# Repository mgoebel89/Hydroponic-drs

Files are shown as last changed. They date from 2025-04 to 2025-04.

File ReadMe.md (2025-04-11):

# What the project is about

**DISCLEMER:** This project was first and foremost created as a workshop for the **"SMART GREEN ISLAND MAKEATHON 2025 on Gran Canaria."**

Therefore, please keep the following in mind:

- The workshop was designed for students aged 15 to 17.

- The project served as an introduction to the world of technology for students.

- Based on the two points mentioned above, the hydroponic system is intentionally designed to be minimalistic. The system was not designed or tested for long-term use, though it is fully automatic and functional.

- Since the workshop was conducted by coaches who assisted the participants at every step, the provided instructions, explanations, files, and plans may leave some aspects out or be incomplete.

- The provided documentation may contain seemingly unnecessary information that is not vital to the assembly

## This guide will show you

- How to build a hydroponic system yourself and how to apply technological methods such as:
  - ESP32 Microcontroller programming in Micropython
  - Implementing PH and EC sensors
- Essential knowledge & concepts to apply or perhaps even expand upon your own hydroponic projects  

## Prerequisites

- Soldering equipment
- Basic coding knowledge
- 3D printer

## Quicklinks

[Bill of materials](BoM.md)

- List of required components and parts to get started

[Build instructions](construction/Instructions.md)

- Instrunctions with images

[3D-Printed Parts](parts)

- Required 3D-printed parts to build the hydroponic system

[Electronics](electronics)

- PH-Probe Instructions
- Additional knowledge on pH-values and conductivity

[Software](src)

- Micropython code for the ESP32 microcontroller

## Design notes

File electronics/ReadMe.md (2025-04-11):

# Details on the sensors can be found under

- [EC](EC-Probe.md)
- [PH](PH-Probe.md)

the `ibom.html` contains the BoM of the PCB and a plan for setting the PCB components.

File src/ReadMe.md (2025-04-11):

# This folder contains source files for different usecases

- `time_control.py` is ment to periodicaly fill the container and let it empty out.
  - the time it takes to fill and empty have to be measured and updated in the code manually.
  - `time_on` should be just over the time it takes for the container to start draining.
  - `time_off` should be set to the time it takes for the system to drain added to the time you want between system flushes
  - sugested flush timing, once every 30 minutes
- `calibrate_ph.py` for usage see [PH-Probe](../electronics/PH-Probe.md)
- `fill_sense_control.py` is a more sophisticated version of `time_control.py` that detects waterlevel and automatically fills the container when it is empty and stops when it is full.
  - for instructions on how to set up the sensor see [FillSense](../construction/FillSense.md)

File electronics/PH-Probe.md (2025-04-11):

# PH Probe Instructions

**The E-201-C sensor is not suitable for continuous deployment**, it should only be used to sporadically measure PH when refining water.

The PH-Probe has to be calibrated using `calibrate_ph.py`\

1. Connect the probe to the normalizer board.
2. Connect the normalizer board to the control-PCB.
3. Run the `calibrate_ph.py` script on the controller.
4. Put the probe into a solution with a known PH.
5. Use the potentiometer on the normalizer board to adjust the PH output to match the solution's PH.

for more details on ideal values, see [pH-values](PH and Conductivity.md)

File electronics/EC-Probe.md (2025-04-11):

# EC Probe Disclaimer

The EC-Probe (TDS sensor) depends on temperature measurements and can, therefore not be used with the current setup.

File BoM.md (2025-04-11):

# Parts and components

## Tables of content

| Electronic Components | Requirements |
|---|---|
| ESP 32 Microcontroller | ESPRESSIF C6-Mini-1|
| 5V Waterpump |USB-A, 1-3W|
| PH-Sensor |E-201-C, 3.3V|
| EC Sensor |TDS, 3.3V|
| **Electric Components**| |
| Powersupply 5V | minimum 5W, USB-A|
| USB-C Cable (Male-Female) |-|
| Breakaway board header | Female, 2.54mm, 15 Pins per Side|
| **Biological Components** | |
| Seedlings|Only leafy plants, take its size into account |
| Granules | Clay granules for potted plants |
| Fertilizer |-|
| **Tools** ||
| Drill |-|
| Isolating Tape |-|
| Sidecutters |-|
| Pliers |-|
| Soldering station |-|
| Tinsolder |-|
| O-Ringe |Amount: 4 per system, Outer diameter 20mm, Inner diameter 15mm|
| **Exterior** | |
| Containers | Not translucent, as dark as possible|
| Silicon Hose | Inner diameter 8mm|
| **3D Printing**| |
| 3D-Printing filament | - |
| **Interior** | |
|Netpot|-|

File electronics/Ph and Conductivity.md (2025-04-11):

# PH and Conductivity in hydroponic systems 

### PH Values

PH-values for leafy plants range between 5 (typically 5.5) and 7.

### Electrical Conductivity

Typical conductivity values for hydroponic systems fall between 1.500 and 2.500 microSiemens per cm (µS/cm).

Our readings are limited to ppm measurements therefore conversion rates from ppm to µS/cm and ppm to mg/L(Salts) are needed.

The following conversions are rough approximations:

- 1 ppm ≈ 1 mg/L
- 1 ppm ≈ 1.5625 µS/cm (640 scale) 

### Plant growth stages

Optimal PPM readings increase according to the plant's growth stage. 
These ranges can be found online.

### How to interpret value readings

Conductivity measurements indicate total amounts of salts in the water such as:

- Nitrogen
- Phosphorus
- Potassium

### Methods to adjust PH and EC

Most simple method is to dillute the nutrient solution by replacing or adding more water.

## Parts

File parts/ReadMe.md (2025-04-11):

# Required number of components for one system: 

1x Drilling template (Drilling_template.3mf)

1x Siphon (Siphon.3mf)

1x Siphon cap (Cap.3mf)

2x Siphon house-adapter (House_adapter.3mf)

1-5x Pot holder (Netpot_holder.3mf)

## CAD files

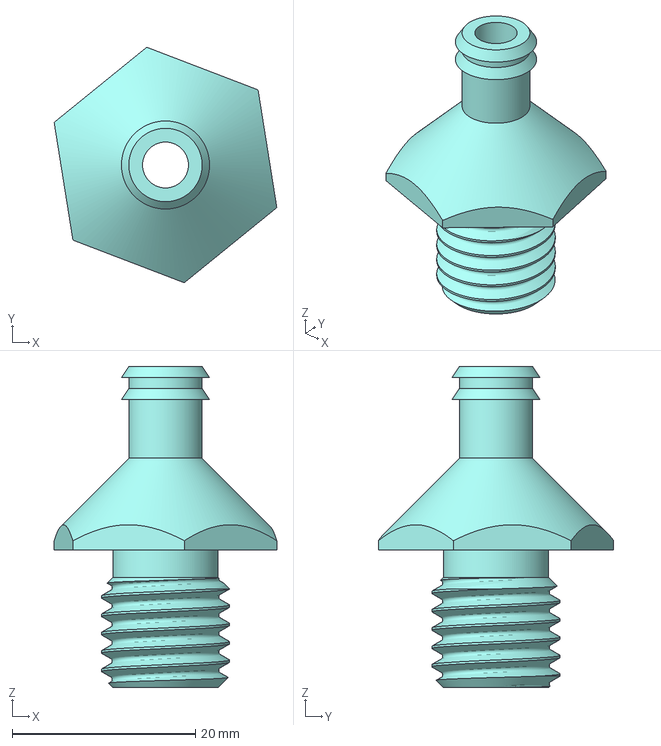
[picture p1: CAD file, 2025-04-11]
parts/Hose_adapter.3mf
24.3 x 25.7 x 35.0 mm

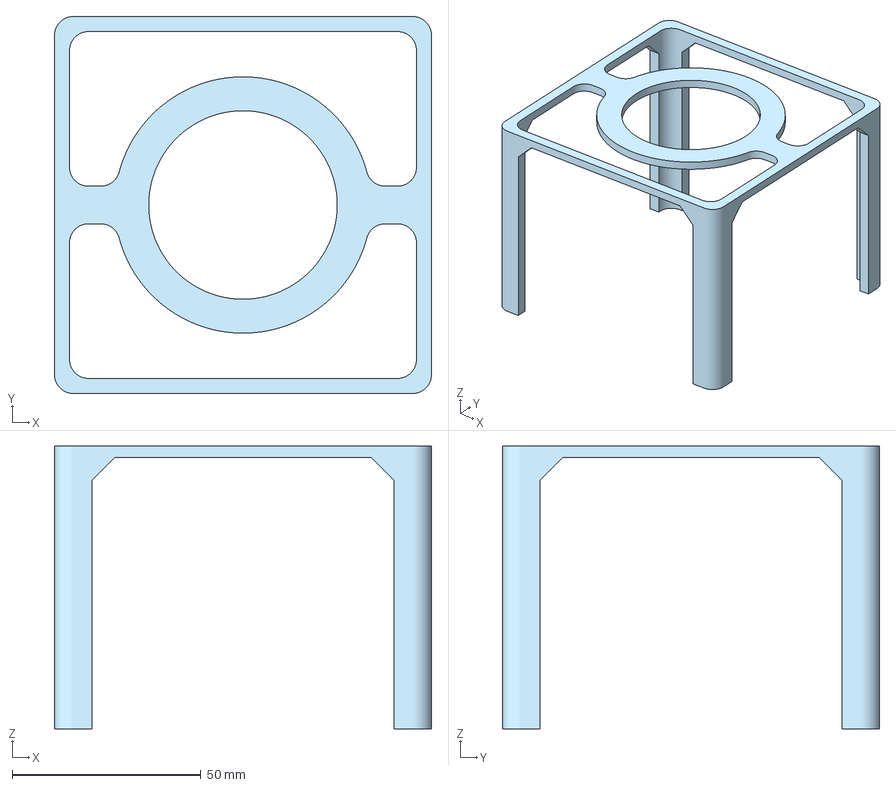
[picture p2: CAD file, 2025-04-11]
parts/Netpot_holder.3mf
100.0 x 100.0 x 75.0 mm

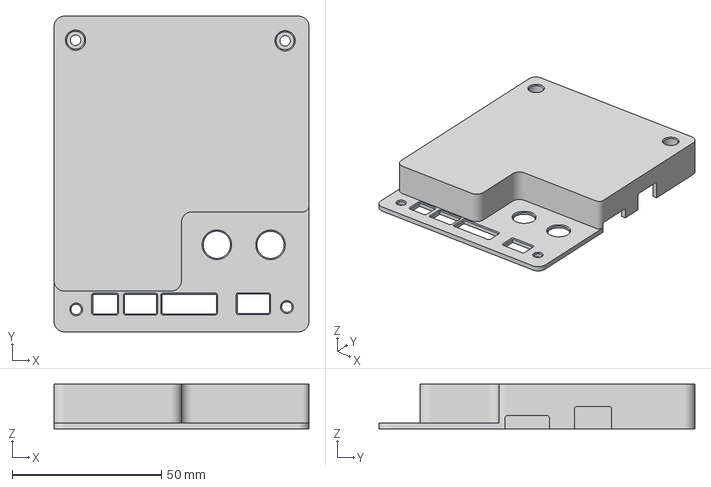
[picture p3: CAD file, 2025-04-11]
parts/Control_board_cover_bottom.3mf
85.4 x 105.7 x 15.0 mm

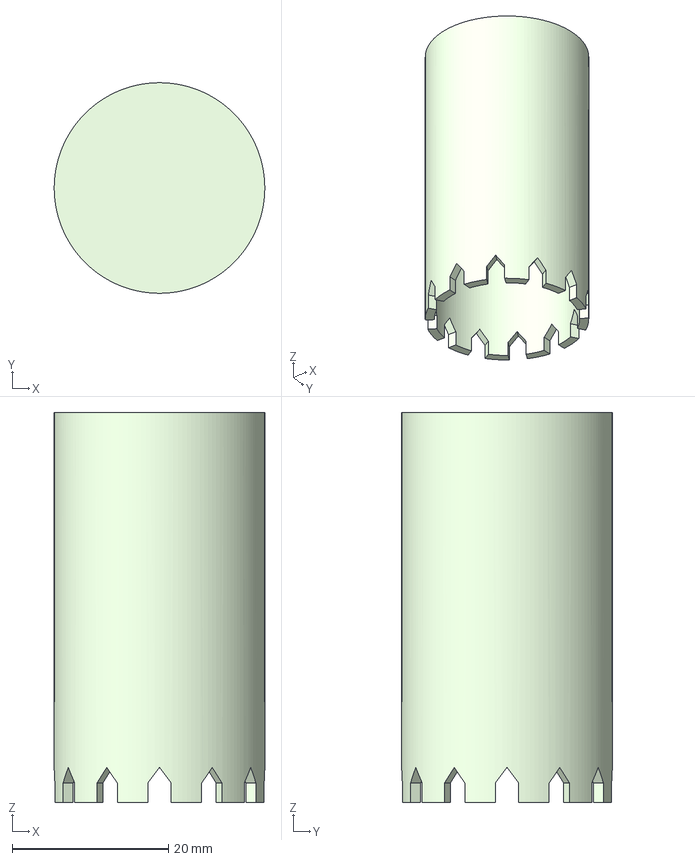
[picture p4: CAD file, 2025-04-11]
parts/Cap.3mf
27.0 x 27.0 x 50.0 mm

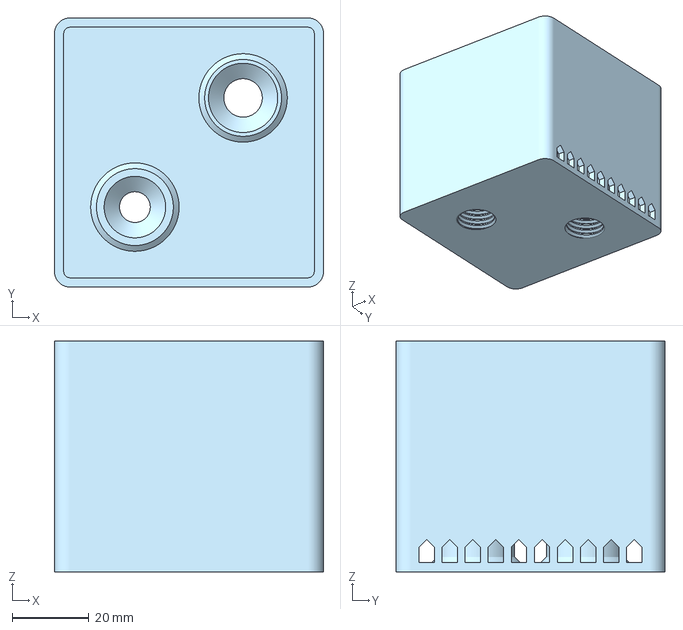
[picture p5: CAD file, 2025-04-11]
parts/Siphon.3mf
70.0 x 70.0 x 60.0 mm

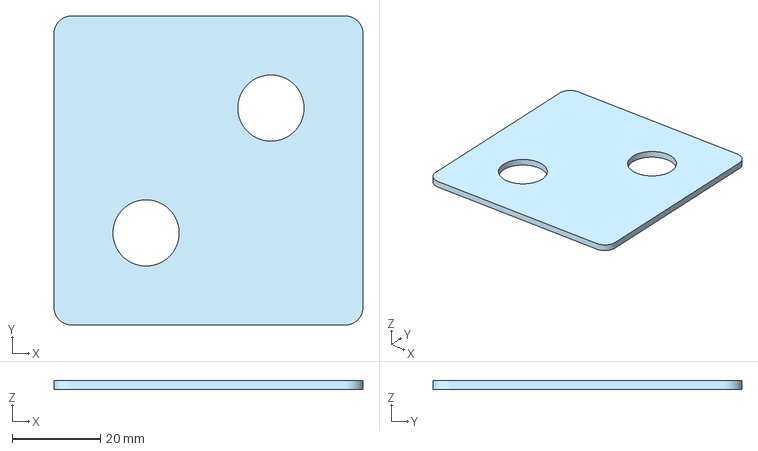
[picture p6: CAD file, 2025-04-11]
parts/Drilling_template.3mf
70.0 x 70.0 x 2.00 mm

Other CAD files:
parts/Control_board_cover_top.3mf

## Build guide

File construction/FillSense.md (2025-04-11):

# Automated Flooding Instructions

To add automated flooding, some changes are required to the board.

1. Solder a wire each to `JP9` and `JP10` on the control board
2. Solder another wire to any of the Ground (`G`) pins
3. Attach the Ground wire to the bottom of the upper container
4. Attach the `JP9` wire to the container wall at about 3/4 of the height of the shorter siphon tube
5. Attach the `JP10` wire to the container wall at a height just above the top of the cap on the shorter tube

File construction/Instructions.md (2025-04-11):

1. Preparing the containers / boxes
   
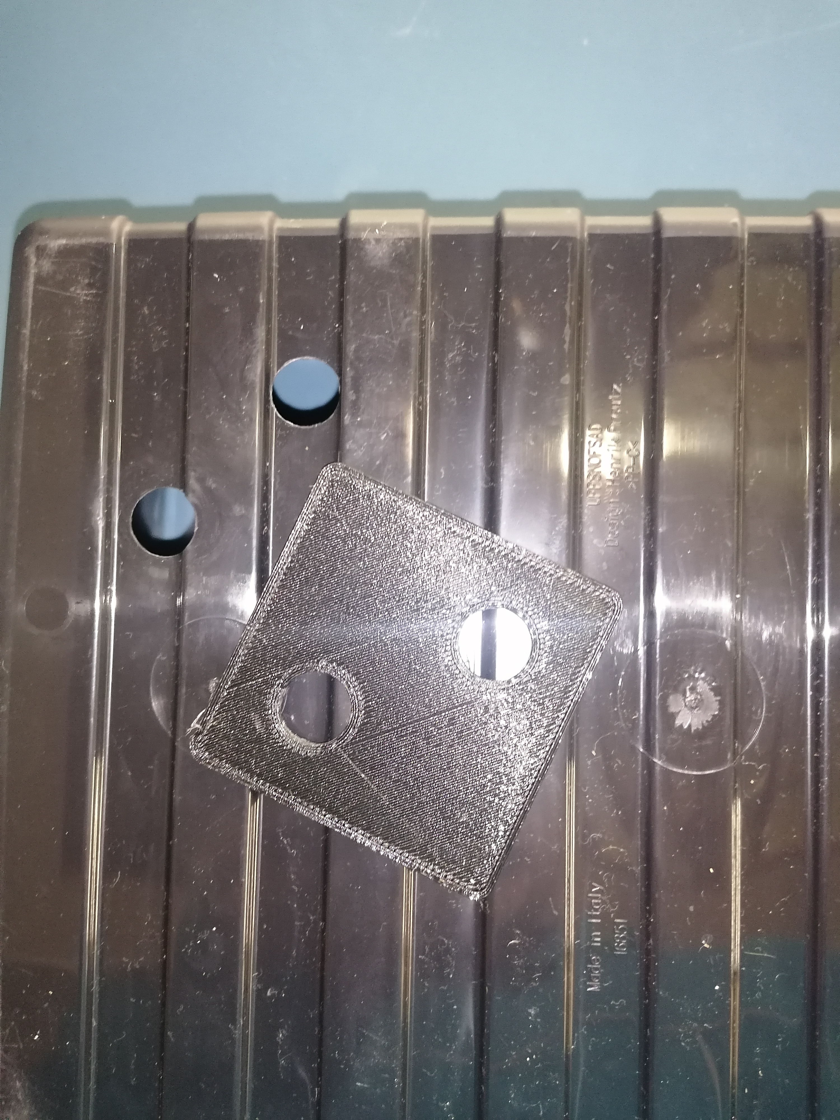
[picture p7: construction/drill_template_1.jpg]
drill_template_1
	1.1 With the help of the provided 3D template, drill two holes into one of the containers. The holes should be in one of the corners of the container. *Be careful before drilling, and make sure that the siphon (the 3D-printed plastic box) fits onto the holes* 

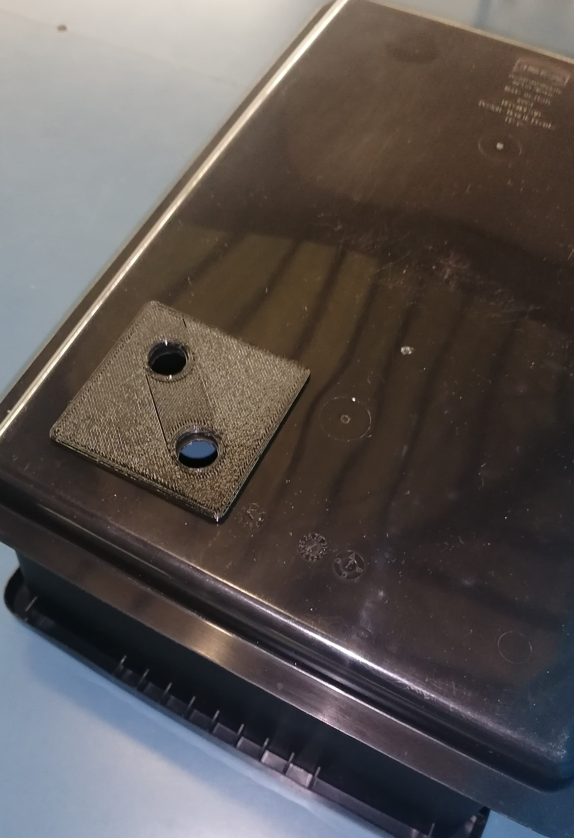
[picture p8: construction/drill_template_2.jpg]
drill_template_2
	1.2 Drill two holes as well into the lid of the container. *Make sure that the holes align!* 
   
	1.3 Cut a groove into the bottom container. *Make it deep enough in order for the lid to close without any problem. Furthermore, do not make it too wide because the cable must fit snugly.*

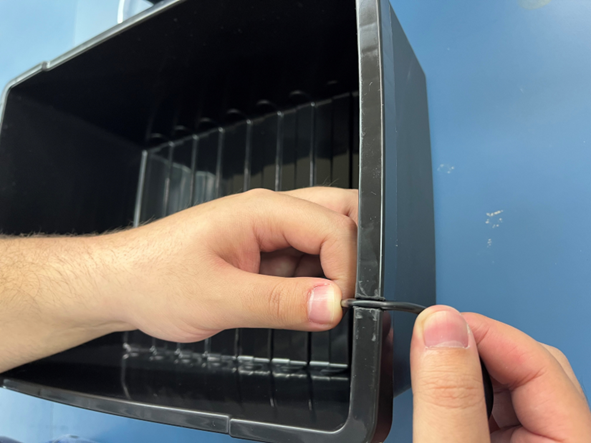
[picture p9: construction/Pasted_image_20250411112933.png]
cut_groove
   .

3. Assembly
   
	2.1 Siphon. 
	2.1.1 Insert the two house-adapters into the holes. *The **O-ring seals** must be on the house-adapters.*
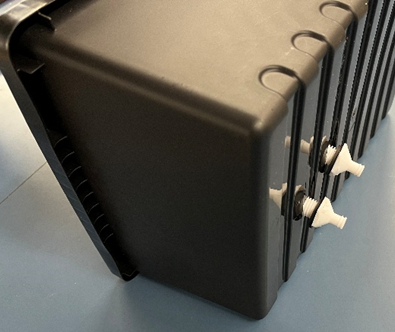
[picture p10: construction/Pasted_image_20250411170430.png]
siphon_assembly_1
   

	2.1.2. Connect the siphons with the house-adapters. *It is important to put **O-ring seals** onto these sides of the house-adapters as well.* 
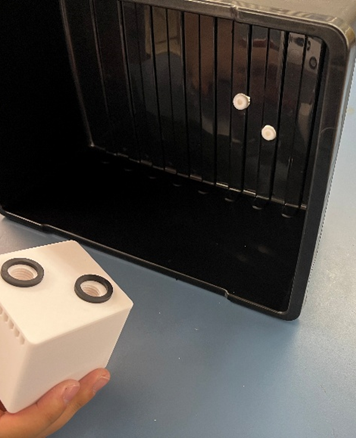
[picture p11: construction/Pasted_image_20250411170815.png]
siphon_assembly_2
	

	2.1.3 If the house-adapters are correctly connected to siphon, tighten them. Screw the house-adapters into the syphon with a wrench, or with the included 3D-designed tool. **The house-adapters must be screwed in tightly in order to make the seals watertight.**
	
	2.2 Installing components
	2.2.1 Attch a 10-15 cm (or longer based on your container) long tube onto the house-adapter of the siphon, which belongs to the **longer pipe**.  The siphon has two pipes, it can be found in the qubical part of the syphon. The shorter is responsible for drainage, therefore it is crucial to get this step right.
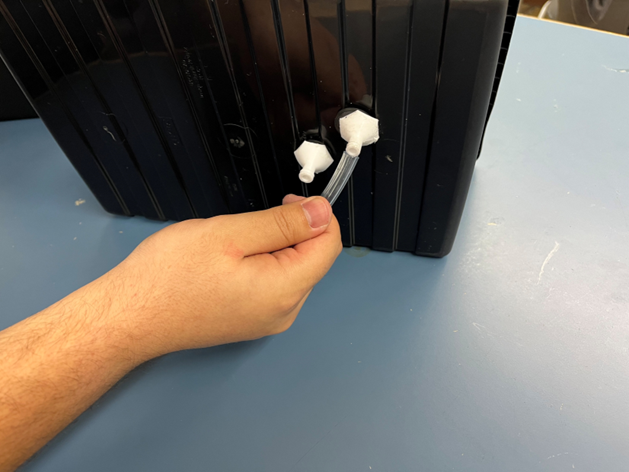
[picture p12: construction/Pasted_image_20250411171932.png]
plastic_tube_to_siphon
   
   
	2.2.2 Place the USB Waterpump into the bottom container below the syphon.
   
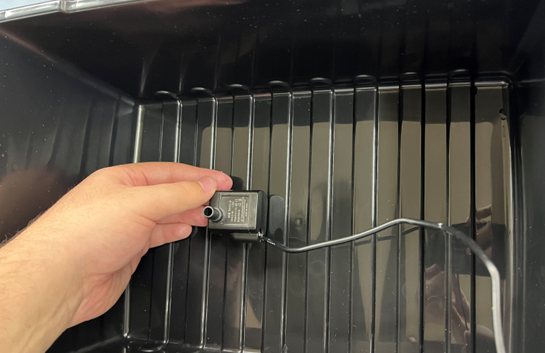
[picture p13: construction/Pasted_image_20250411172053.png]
waterpump_placement
   
   
	2.2.3. Pull the cable through the grooves carved out in step 1.3.
   
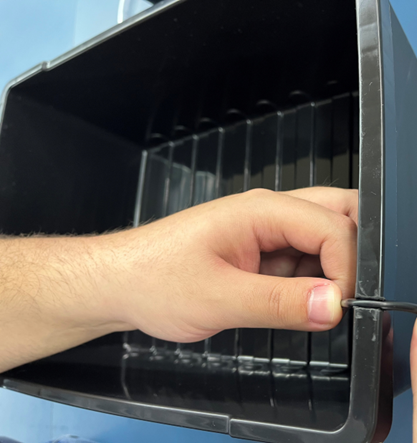
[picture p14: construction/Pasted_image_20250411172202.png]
cable_put_into_groove
	

	2.3. Connecting parts
   
	2.3.1. Feed the plastic tube and the house-adapters of the siphon through the holes in the lid.
   
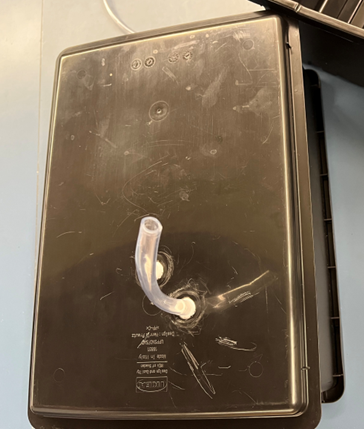
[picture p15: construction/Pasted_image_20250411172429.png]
siphon_lid
	

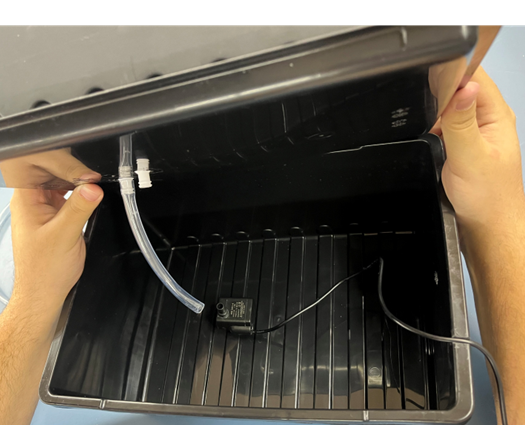
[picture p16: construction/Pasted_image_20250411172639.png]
tube_waterpump_connection
	2.3.2. Attach the tube of the siphon with the water pump. *This step may require multiple attempts, as based on the length and sturdiness of the tube, the waterpump can get dislodged when the upper container is placed on the lower one.* 
   
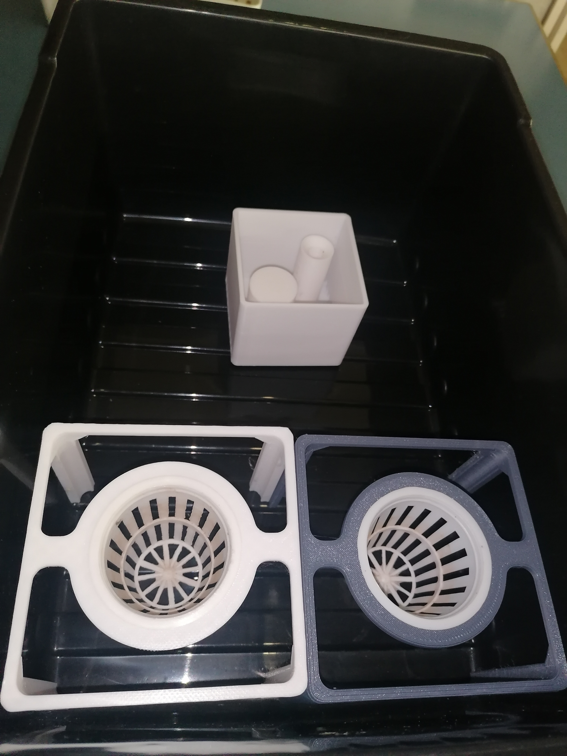
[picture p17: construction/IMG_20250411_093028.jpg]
final_assembly
	2.3.3. Put the siphon cap onto the shorter pipe of the syphon.

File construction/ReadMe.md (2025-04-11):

# hier werden alle konstruktionspläne oder Platinendetails hinterlegt

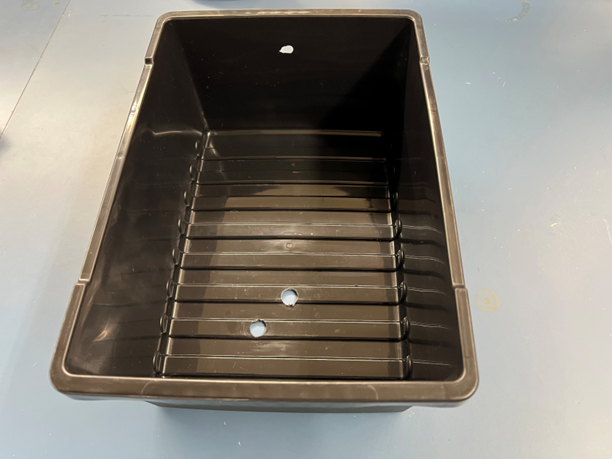
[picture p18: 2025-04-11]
construction/Pasted_image_20250411092005.png

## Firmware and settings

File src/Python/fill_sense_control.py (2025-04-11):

from machine import Pin, Timer
from time import sleep_ms

PIN_PUMP = 23
PIN_LED_GREEN = 21
PIN_LED_RED = 20
PIN_BUTTON_GREEN = 19
PIN_BUTTON_RED = 18
PIN_FILL_HIGH = 9
PIN_FILL_LOW = 15

# Set timings
counter_period = 1000 # in ms
time_off = 5 # in increments of counter period
time_rest = 10 # in increments of counter period
time_drain = 15 # in increments of counter period

timer_count = 0 # used for time keeping
sequence = 0 # used to keep up execution order
state = False # used to track automation state
filling = False # used to keep track of automation state
draining = False # used to keep track of automation state

# Set to True to get debug Prints
debug = False
# Set debug interval in ms
debug_interval = 100

# Initialize output pins
pump = Pin(PIN_PUMP, Pin.OUT)
led_g = Pin(PIN_LED_GREEN, Pin.OUT)
led_r = Pin(PIN_LED_RED, Pin.OUT)

# Sets output pins to known state
pump.off()
led_g.off()
led_r.off()

# Initialize input pins
btn_g = Pin(PIN_BUTTON_GREEN, Pin.IN, Pin.PULL_DOWN)
btn_r = Pin(PIN_BUTTON_RED, Pin.IN, Pin.PULL_DOWN)
fill_high = Pin(PIN_FILL_HIGH, Pin.IN, Pin.PULL_UP)
fill_low = Pin(PIN_FILL_LOW, Pin.IN, Pin.PULL_UP)

def print_debug(t):
    global pump, led_g, led_r, btn_g, btn_r, fill_high, fill_low, timer_count, sequence, state, filling
    print(f"==================")
    print(f"Pump: {pump.value()}")
    print(f"LED_G: {led_g.value()}")
    print(f"LED_R: {led_r.value()}")
    print(f"BTN_G: {btn_g.value()}")
    print(f"BTN_R: {btn_r.value()}")
    print(f"FILL_HIGH: {fill_high.value()}")
    print(f"FILL_LOW: {fill_low.value()}")
    print(f"Period count: {timer_count}")
    print(f"Sequence: {sequence}")
    print(f"State: {state}")
    print(f"Filling: {filling}")
    print(f"Draining: {draining}")

if debug:
    debug_timer = Timer(2)
    debug_timer.init(period=debug_interval, mode=Timer.PERIODIC, callback=print_debug)

def tf(t):
    # Increments timer variable
    global timer_count
    timer_count += 1

# Sets up timer
tim = Timer(0)

def callback_button_green(pin):
    # Called when green button is pressed
    global state, pump, tim, debug, sequence, timer_count, filling, draining
    if debug:
        print(f"Green, State: {state}")
    if state:
        pass
    else:
        pump.on()
        filling = True
        draining = False
        sequence = 1
        timer_count = 0
        state = True
    tim.init(period=counter_period, mode=Timer.PERIODIC, callback=tf) # Enable timer

def callback_button_red(pin):
    # Called when red button is pressed
    global state, pump, tim, debug, sequence, timer_count, filling
    if debug:
        print(f"Red, State: {state}")
    tim.deinit() # Disable timer
    if state:
        sequence = 0
        timer_count = 0
        state = False
        if filling:
            pump.on()
    else:
        pass

# Setup callback functions for button-press interrupts
btn_g.irq(trigger=Pin.IRQ_RISING, handler=callback_button_green)
btn_r.irq(trigger=Pin.IRQ_RISING, handler=callback_button_red)

while True:
    # Update LEDs to reflect execution status
    led_g.value(state)
    led_r.value(not state)
    
    # Check if automation isn't running, disable pump after full
    if not state and filling:
        if fill_high.value() == 0:
            pump.off()
            filling = False
            sequence = 0
            timer_count = 0

    # Run sequence step 0 if automation is running and timer has exceeded threshold
    if state and sequence == 0 and timer_count >= time_off:
        pump.on()
        filling = True
        draining = False
        sequence = 1
        timer_count = 0

    # Run sequence step 1 if automation is running and water has reached the lower threshold
    if state and sequence == 1 and fill_low.value() == 0:
        pump.off()
        filling = True
        draining = False
        sequence = 2
        timer_count = 0
    
    # Run sequence step 2 if automation is running and timer has exceeded threshold
    if state and sequence == 2 and timer_count >= time_rest:
        pump.on()
        filling = True
        draining = False
        sequence = 3
        timer_count = 0

    # Run sequence step 3 if automation is running and water has reached the upper threshold
    if state and sequence == 3 and fill_high.value() == 0:
        pump.off()
        filling = False
        draining = True
        sequence = 4
        timer_count = 0

    # Run sequence step 4 if automation is running and timer has exceeded threshold
    if state and sequence == 4 and timer_count >= time_drain:
        draining = False
        sequence = 0
        timer_count = 0

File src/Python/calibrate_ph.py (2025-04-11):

from machine import ADC, Pin
import time

# Setup ADC (GPIO36 on ESP32)
ph_pin = ADC(Pin(36))       # Change to your actual pin
ph_pin.atten(ADC.ATTN_11DB)  # For 0-3.6V input range
ph_pin.width(ADC.WIDTH_12BIT)

def read_ph():
    raw = ph_pin.read()
    voltage = raw / 4095 * 3.3  # 12-bit ADC to voltage
    ph = 7 + ((2.5 - voltage) * 3.5)  # Rough linear mapping
    return ph, voltage

while True:
    ph, voltage = read_ph()
    print("pH:", round(ph, 2), "Voltage:", round(voltage, 2), "V")
    time.sleep(1)

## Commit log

2025-03-18 Added python with pin definitions
2025-04-10 Upload BoM
2025-04-10 Update BoM.md
    Edit: Spelling
2025-04-10 added ph-probe.md
2025-04-11 Added calibration file for PH-Probe updated PH-Probe.md
2025-04-11 Added 3D files
    [Cap.3mf, Control_board_bottom.3mf, Control_board_top.3mf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]
2025-04-11 Renamed files
    [Control_board_cover_bottom.3mf, Control_board_cover_top.3mf]
2025-04-11 Updated Ph and Conductivity.md
    Added conversion rates namely:
    > ppm to mg/L (Salts)
    > ppm to microSiemens/cm
    Additional pieces of information about PPM ranges between varying plant growth stages
    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
2025-04-11 addded EC-Probe Disclaimer
2025-04-11 fixed typo in electronics/EC-Probe.md
2025-04-11 Update BoM.md
    Added:
    Missing Component:
    - 3D-Printed Netpot
    - 3D Printing filament
    Missing Category:
    - 3D Printing
2025-04-11 Update BoM.md
    Edit: Minor error
    > Misplaced component into Requirement column
2025-04-11 Update BoM.md
    Fixed Minor error:
    > Misplaced categories
2025-04-11 update ReadMe.md and PH-Probe.md
